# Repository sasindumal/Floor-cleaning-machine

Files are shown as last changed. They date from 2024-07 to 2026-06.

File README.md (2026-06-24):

# 🤖 Autonomous Floor Cleaning Machine — R1

> **Design Prototype Project** | Group R1 | Sasindu Malhara (2022/E/126)

An autonomous floor-cleaning robot designed and built from scratch, featuring dual-mode operation (manual Bluetooth control and ML-powered automatic navigation), custom mechanical design, CoppeliaSim simulation, and a machine learning model embedded directly into Arduino firmware.

---

## 📖 Table of Contents

- [Overview](#overview)
- [Features](#features)
- [System Architecture](#system-architecture)
- [Hardware Components](#hardware-components)
- [Software & Tech Stack](#software--tech-stack)
- [Project Structure](#project-structure)
- [Operating Modes](#operating-modes)
  - [Manual Mode (Bluetooth)](#manual-mode-bluetooth)
  - [Automatic Mode (ML-based)](#automatic-mode-ml-based)
- [Machine Learning Model](#machine-learning-model)
- [Simulation](#simulation)
- [Mechanical Design](#mechanical-design)
- [Code Versions](#code-versions)
- [Pin Configuration](#pin-configuration)
- [Bluetooth Command Reference](#bluetooth-command-reference)
- [Setup & Deployment](#setup--deployment)
- [Reinforcement Learning Notes](#reinforcement-learning-notes)
- [Videos & Demos](#videos--demos)
- [Author](#author)

---

## Overview

The **Autonomous Floor Cleaning Machine R1** is a prototype robotic system capable of navigating indoor environments while performing floor-cleaning tasks. The robot integrates:

- A **dual H-bridge motor driver** (L298N) for differential drive
- **4 ultrasonic sensors** for 360° obstacle detection
- A **Bluetooth module (HC-05)** for wireless manual control
- A **machine learning model** trained on sensor data and compiled into C++ to run directly on an Arduino Uno
- A **roller brush**, **mop**, **water pump**, and **dryer** for complete floor-cleaning functionality
- **SolidWorks CAD** drawings and **CoppeliaSim** simulation models for design validation

---

## Features

- ✅ **Manual Bluetooth Control** — real-time directional commands via serial/Bluetooth
- ✅ **Autonomous Obstacle-Avoidance Navigation** — ML model predicts movement decisions from ultrasonic sensor readings
- ✅ **Embedded ML on Arduino** — trained model converted to C++ (`predict()` function) and flashed to Arduino Uno
- ✅ **Complete Cleaning System** — roller brush, mop motor, water pump, and dryer actuators
- ✅ **Dual-mode switching** — seamlessly switch between manual and auto mode over Bluetooth
- ✅ **CoppeliaSim Simulation** — multiple simulation versions for testing before hardware deployment
- ✅ **SolidWorks CAD** — full mechanical assembly with custom parts
- ✅ **URDF Models** — ROS-compatible robot description files (3 versions)

---

## System Architecture

```
┌─────────────────────────────────────────────────────────┐
│                     Arduino Uno                         │
│                                                         │
│  ┌──────────┐   ┌──────────────┐   ┌─────────────────┐ │
│  │ Bluetooth│   │  Ultrasonic  │   │  ML predict()   │ │
│  │  HC-05   │──▶│  4x Sensors  │──▶│  (C++ model)    │ │
│  └──────────┘   └──────────────┘   └────────┬────────┘ │
│                                             │           │
│  ┌──────────────────────────────────────────▼────────┐  │
│  │              Motor Control (L298N)                │  │
│  │         Left Motor  |  Right Motor                │  │
│  └──────────────────────────────────────────────────┘  │
│                                                         │
│  ┌──────────┐  ┌─────┐  ┌──────┐  ┌─────┐             │
│  │  Roller  │  │ MOP │  │ Pump │  │ Dry │             │
│  │  Brush   │  │Motor│  │      │  │     │             │
│  └──────────┘  └─────┘  └──────┘  └─────┘             │
└─────────────────────────────────────────────────────────┘
```

---

## Hardware Components

| Component | Model / Spec | Purpose |
|---|---|---|
| Microcontroller | Arduino Uno | Main controller |
| Motor Driver | L298N Dual H-Bridge | Controls left & right drive motors |
| Drive Motors | DC Motors (x2) | Differential drive locomotion |
| Ultrasonic Sensors | HC-SR04 (x4) | Front-left, front-right, left, right obstacle detection |
| Bluetooth Module | HC-05 | Wireless serial communication |
| Roller Brush Motor | DC Motor | Floor brushing/sweeping |
| Mop Motor | DC Motor | Wet mopping actuation |
| Water Pump | KDP-370EB 12V | Water dispensing for mopping |
| Dryer | DC Motor | Floor drying after mopping |
| Battery | KT-1213 12V 1.3Ah AGM Lead-Acid | Main power supply |
| Chassis | Custom SolidWorks design | Machine body & mounting |
| Wheels | 85mm custom wheels | Locomotion |
| Vacuum Fan | 80mm vacuum fan | Debris suction |

---

## Software & Tech Stack

| Layer | Technology |
|---|---|
| Firmware | Arduino C++ (.ino) |
| ML Training | Python, Jupyter Notebook, scikit-learn / neural network |
| ML Deployment | C++ model code embedded in Arduino firmware |
| Simulation | CoppeliaSim (.ttt scene files) |
| CAD Design | SolidWorks (.SLDPRT, .SLDASM) |
| Robot Description | URDF (ROS-compatible) |
| Data | CSV dataset for ML training |
| RL Research | Unity ML-Agents (referenced in RL notes) |

---

## Project Structure

```
02 Floor-cleaning-machine/
│
├── Code/                                    # All firmware and software
│   ├── Floor-Cleanig-machine-R1/
│   │   └── Floor-Cleanig-machine-R1.ino    # Revision 1 firmware
│   ├── Floor-Cleanig-machine-R1-Final/
│   │   └── Floor-Cleanig-machine-R1-Final.ino  # Final production firmware
│   ├── Floor_Cleanig_machine_R1_Final_test/
│   │   └── (test sketches)
│   ├── ML/
│   │   ├── Floor-Cleaning-Machine-ML.ipynb  # ML training notebook
│   │   ├── Floor cleaning machine ML dataset.csv  # Training dataset
│   │   ├── model.json                        # Trained model (JSON)
│   │   ├── Floor-Cleaning-Machine-ML.pdf    # ML documentation
│   │   ├── c++ model code.txt               # C++ exported model code
│   │   └── cpp-model-check.cpp              # C++ model integration test
│   ├── US_check/
│   │   └── US_check.ino                     # Ultrasonic sensor test sketch
│   ├── check-sensors/
│   │   └── check-sensors.ino                # Sensor + motor diagnostic sketch
│   ├── Code 2.0.txt                         # Code snapshot v2.0
│   └── Code 3.0.txt                         # Code snapshot v3.0
│
├── Machine/                                 # Mechanical design files
│   ├── CoppeliaSim/
│   │   ├── Machine.ttt                      # Simulation scene v1
│   │   ├── Machine 2.0.ttt                  # Simulation scene v2
│   │   ├── Machine 3.0.ttt                  # Simulation scene v3
│   │   ├── Machine 4.0.ttt                  # Simulation scene v4
│   │   ├── Machine 5.0.ttt                  # Simulation scene v5
│   │   └── Machine-ML/                      # ML-enabled simulation
│   ├── Drawing/                             # SolidWorks parts & assembly
│   │   ├── Machine.SLDASM                   # Full machine assembly
│   │   ├── Body.SLDPRT                      # Machine body
│   │   ├── Arduino Uno.SLDPRT              # Arduino Uno model
│   │   ├── HCSR04 Ultrasonic Sensor.SLDPRT # HC-SR04 model
│   │   ├── L298N_Stepper_motor_driver.SLDPRT
│   │   ├── Roller Brush.SLDPRT
│   │   ├── 85mm_Wheel.SLDPRT
│   │   ├── KT-1213 Battery.SLDASM          # Battery assembly
│   │   └── ... (27 component files total)
│   ├── URDF/                                # ROS robot description v1
│   ├── URDF 2.0/                            # ROS robot description v2
│   └── URDF 3.0/                            # ROS robot description v3
│
├── RL/
│   └── Rl steps.txt                         # Reinforcement learning research notes
│
├── Videos/                                  # Physical build & simulation demos
│   ├── Simulation.mkv                       # CoppeliaSim simulation video
│   ├── Cad design.mkv                       # SolidWorks CAD walkthrough
│   └── VID-20240806-*.mp4                   # Physical prototype test videos
│
├── .gitignore
└── README.md
```

---

## Operating Modes

### Manual Mode (Bluetooth)

The robot defaults to **manual mode** on startup. Commands are sent via the HC-05 Bluetooth module (serial at 9600 baud).

The robot receives a single character over serial and executes the corresponding action:

| Command | Action |
|---|---|
| `F` | Move **Forward** + activate pump |
| `f` | Stop (forward stop) |
| `B` | Move **Backward** |
| `b` | Stop (backward stop) |
| `L` | Turn **Left** |
| `l` | Stop (left stop) |
| `R` | Turn **Right** |
| `r` | Stop (right stop) |
| `S` | **Stop** all drive motors |
| `N` | Turn **Pump ON** |
| `n` | Turn **Pump OFF** |
| `M` | Turn **Mop Motor ON** |
| `m` | Turn **Mop Motor OFF** |
| `K` | Turn **Roller Brush ON** |
| `k` | Turn **Roller Brush OFF** |
| `D` | Turn **Dryer ON** |
| `d` | Turn **Dryer OFF** |
| `A` | Switch to **Automatic Mode** |

### Automatic Mode (ML-based)

Activated by sending `A` over Bluetooth. The robot:

1. **Reads** all 4 ultrasonic sensors (front-left, front-right, left, right)
2. **Feeds** the sensor distances into the embedded `predict()` function (C++ ML model)
3. **Executes** the predicted movement command:

| Prediction | Action |
|---|---|
| `0` | Turn Left |
| `1` | Turn Right |
| `2` | Move Backward |
| `3` | Move Forward |

Send `X` to exit automatic mode and return to manual control.

---

## Machine Learning Model

The navigation decision model was trained in Python using sensor distance data.

### Training Pipeline

1. **Dataset**: `Floor cleaning machine ML dataset.csv` — collected sensor readings labeled with correct movement decisions
2. **Training**: Jupyter Notebook (`Floor-Cleaning-Machine-ML.ipynb`) — model trained using scikit-learn / neural network
3. **Export**: Model exported to `model.json` and converted to C++ code (`c++ model code.txt`)
4. **Deployment**: The C++ `predict(float[])` function is compiled directly into Arduino firmware — **no external libraries or runtime needed**

### Inputs / Outputs

```
Inputs:  [front_distance, left_distance, right_distance]  (float, in cm)
Output:  int prediction -> { 0: Left, 1: Right, 2: Backward, 3: Forward }
```

---

## Simulation

CoppeliaSim simulation scenes are located in `Machine/CoppeliaSim/`. Multiple versions were developed iteratively:

| File | Version | Description |
|---|---|---|
| `Machine.ttt` | v1.0 | Initial simulation |
| `Machine 2.0.ttt` | v2.0 | Updated physics |
| `Machine 3.0.ttt` | v3.0 | Sensor integration |
| `Machine 4.0.ttt` | v4.0 | Full sensor + motor simulation |
| `Machine 5.0.ttt` | v5.0 | Final simulation |
| `Machine-ML/` | ML | ML-integrated simulation |

A simulation demo video is available at `Videos/Simulation.mkv`.

---

## Mechanical Design

The machine body was designed in **SolidWorks** with a full assembly (`Machine.SLDASM`) comprising 27 custom and standard parts:

- Custom body chassis and mounting brackets
- DC motor + bracket assemblies
- 85mm drive wheels
- Roller brush assembly
- HC-SR04 ultrasonic sensor mounts
- L298N motor driver mount
- Arduino Uno and HC-05 Bluetooth module placements
- 12V AGM lead-acid battery compartment
- 80mm vacuum fan housing

A CAD design walkthrough video is available at `Videos/Cad design.mkv`.

**URDF models** (3 versions) are provided for ROS-based simulation or further robot modeling.

---

## Code Versions

| Version | File | Description |
|---|---|---|
| v1.0 (R1) | `Code/Floor-Cleanig-machine-R1/Floor-Cleanig-machine-R1.ino` | Initial prototype firmware |
| v2.0 | `Code/Code 2.0.txt` | Intermediate version snapshot |
| v3.0 | `Code/Code 3.0.txt` | Feature-complete snapshot |
| v1-Final | `Code/Floor-Cleanig-machine-R1-Final/Floor-Cleanig-machine-R1-Final.ino` | **Production firmware with embedded ML** |
| Test | `Code/Floor_Cleanig_machine_R1_Final_test/` | Test sketches |
| Sensor check | `Code/check-sensors/check-sensors.ino` | Sensor + motor diagnostic |
| US check | `Code/US_check/US_check.ino` | Ultrasonic-only diagnostic |

---

## Pin Configuration

### Drive Motors (via L298N)

| Pin | Arduino | Function |
|---|---|---|
| `L1` | D2 | Left motor direction A |
| `L2` | D4 | Left motor direction B |
| `LENB` | D3 (PWM) | Left motor enable (speed) |
| `R1` | D5 (PWM) | Right motor direction A |
| `R2` | D7 | Right motor direction B |
| `RENB` | D6 (PWM) | Right motor enable (speed) |

### Cleaning Actuators

| Pin | Arduino | Function |
|---|---|---|
| `Roller` | D8 | Roller brush motor |
| `MOP` | D9 | Mop motor |
| `Pump` | D12 | Water pump |
| `Dry` | D11 | Dryer motor |

### Ultrasonic Sensors (HC-SR04)

| Sensor | Trig Pin | Echo Pin |
|---|---|---|
| Front-Left (`Usfl`) | A1 | A0 |
| Front-Right (`Usfr`) | D13 | D10 |
| Left (`Usl`) | A3 | A2 |
| Right (`Usr`) | A5 | A4 |

---

## Bluetooth Command Reference

Connect a Bluetooth terminal app (e.g., **Serial Bluetooth Terminal** on Android) to the HC-05 module:

- **Baud rate**: `9600`
- **Device name**: `HC-05` (default)
- **Pairing PIN**: `1234` or `0000`

Send single characters as listed in the [Manual Mode](#manual-mode-bluetooth) section above.

---

## Setup & Deployment

### Prerequisites

- [Arduino IDE](https://www.arduino.cc/en/software) (v1.8+ or v2.x)
- [CoppeliaSim](https://www.coppeliarobotics.com/) (for simulation)
- [SolidWorks](https://www.solidworks.com/) (for CAD files)
- Python 3.x + Jupyter Notebook (for ML training)

### Flash Firmware

1. Open `Code/Floor-Cleanig-machine-R1-Final/Floor-Cleanig-machine-R1-Final.ino` in Arduino IDE
2. Select **Board**: `Arduino Uno`
3. Select the correct **Port** for your connected Arduino
4. Click **Upload**

### Run Simulation

1. Open CoppeliaSim
2. Load `Machine/CoppeliaSim/Machine 5.0.ttt` (latest simulation)
3. Press **Play** to start the simulation

### Retrain ML Model (Optional)

1. Open `Code/ML/Floor-Cleaning-Machine-ML.ipynb` in Jupyter Notebook
2. Ensure the dataset `Floor cleaning machine ML dataset.csv` is in the same directory
3. Run all cells to retrain and export the model
4. Copy the generated C++ `predict()` function into the main `.ino` firmware file

---

## Reinforcement Learning Notes

The `RL/Rl steps.txt` file documents research into using **Reinforcement Learning** (RL) as an alternative navigation approach:

- **Simulation environment**: Unity with ML-Agents Toolkit
- **Algorithm considered**: PPO (Proximal Policy Optimization), DQN (Deep Q-Networks)
- **Reward design**: Obstacle avoidance + staying on track
- **Deployment challenge**: Converting RL model for Arduino's limited hardware

> The current production firmware uses a **supervised ML model** (trained on labeled sensor data) rather than RL, as it is more practical for Arduino deployment.

---

## Videos & Demos

| File | Description |
|---|---|
| `Videos/Simulation.mkv` | CoppeliaSim simulation demo |
| `Videos/Cad design.mkv` | SolidWorks CAD design walkthrough |
| `Videos/VID-20240806-WA0002.mp4` | Physical prototype test |
| `Videos/VID-20240806-WA0009.mp4` | Obstacle avoidance test |
| `Videos/VID-20240806-WA0015.mp4` | Full cleaning run demo |
| `Videos/2024-08-08 08-30-12.mkv` | Final build test session |

---

## Author

**Sasindu Malhara** — `2022/E/126`
Group R1 — Design Prototype Project

---

*This project was developed as a design prototype for academic purposes. All code and design files are owned by Group R1.*

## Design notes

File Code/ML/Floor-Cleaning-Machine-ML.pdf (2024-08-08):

## Floor-Cleaning-Machine-ML

August 8, 2024

## 1 Floor Cleaning Machine ML Model with Random Forest

This code is fully owned by Sasindu Malhara (2022/E/126,University of jaffna) group R1.

### 1.0.1 Import libraries

[1]: import pandas as pd
from sklearn.model_selection import train_test_split from sklearn.ensemble import RandomForestClassifier import json
from sklearn.metrics import accuracy_score

### 1.0.2 Import data

[2]: data=pd.read_csv("D:\\Sem 3 - E22\\E22\\DP\\Our\\2. ↪0\\Git\\Floor-cleaning-machine\\Code\\ML\\Floor cleaning machine ML dataset . ↪csv")

### 1.0.3 Data mapping

[3]: data['next movement'] = data['next movement'].map({' L': 0, 'R': 1, 'B': 2, 'F': ↪ 3})

[4]: data.fillna(0, inplace=True)

[5]: X = data.drop('next movement', axis=1) y = data['next movement']

[6]: X

[6]: | Usf Usl Usr
0 | 1 | 0 | 0
1 | 1 | 1 | 0
2 | 1 | 0 | 1
3 | 1 | 1 | 1
4 | 0 | 0 | 0
59 | 1 | 1 | 1

60 | 0 | 0 | 0
61 | 0 | 1 | 1
62 | 0 | 1 | 0
63 | 0 | 0 | 1

[64 rows x 3 columns]

[7]: y

[7]: 0 | 1.0
1 | 1.0
2 | 0.0
3 | 2.0
4 | 3.0
…
59 | 2.0
60 | 3.0
61 | 3.0
62 | 3.0
63 | 3.0
Name: next movement, Length: 64, dtype: float64

[8]: print('X.shape=', X.shape, 'y.shape=', y.shape)

X.shape= (64, 3) y.shape= (64,)

### 1.0.4 Splitting data

[9]: X_train, X_test, y_train, y_test = train_test_split(X, y, test_size=0.2,␣ ↪random_state=42)

### 1.0.5 Finding best parameters

[11]: from sklearn.model_selection import RandomizedSearchCV from scipy.stats import randint

param_dist = {
'n_estimators': randint(100, 1000), 'max_features': ['auto', 'sqrt', 'log2'], 'max_depth': randint(4, 20), 'min_samples_split': randint(2, 10), 'min_samples_leaf': randint(1, 4), 'bootstrap': [True, False]
}

rf = RandomForestClassifier()
random_search = RandomizedSearchCV(estimator = rf, param_distributions =␣ ↪param_dist, n_iter = 100, cv = 3, n_jobs = -1, verbose =␣ ↪2)
random_search.fit(X_train, y_train)
best_params = random_search.best_params_

Fitting 3 folds for each of 100 candidates, totalling 300 fits

c:\Users\sasin\anaconda3\Lib\site-packages\sklearn\ensemble\_forest.py:424: FutureWarning: `max_features='auto'` has been deprecated in 1.1 and will be removed in 1.3. To keep the past behaviour, explicitly set `max_features='sqrt'` or remove this parameter as it is also the default value for

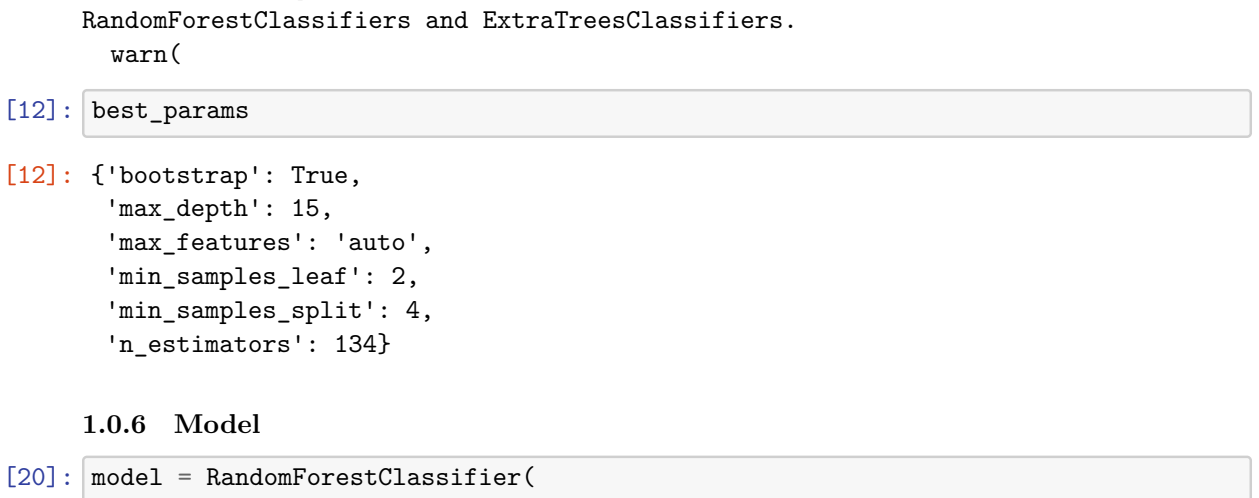
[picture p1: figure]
RandomForestClassifiers and ExtraTreesClassifiers. warn(; [12]: best_params; [12]: {'bootstrap': True, 'max_depth': 15, 'max_features': 'auto', 'min_samples_leaf': 2, 'min_samples_split': 4, 'n_estimators': 134}; 1.0.6 Model; [20]: model = RandomForestClassifier(

bootstrap=True,
max_depth=3,
max_features='auto',
min_samples_leaf=2,
min_samples_split=4,
n_estimators=10
)
model.fit(X_train, y_train)

c:\Users\sasin\anaconda3\Lib\site-packages\sklearn\ensemble\_forest.py:424: FutureWarning: `max_features='auto'` has been deprecated in 1.1 and will be removed in 1.3. To keep the past behaviour, explicitly set `max_features='sqrt'` or remove this parameter as it is also the default value for

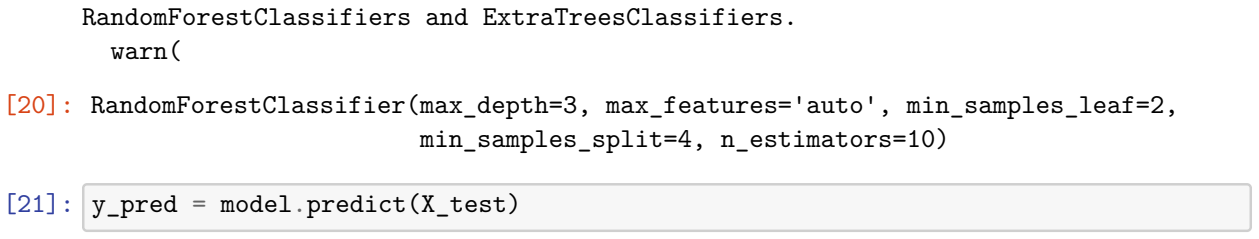
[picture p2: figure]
RandomForestClassifiers and ExtraTreesClassifiers. warn(; [20]: RandomForestClassifier(max_depth=3, max_features='auto', min_samples_leaf=2, min_samples_split=4, n_estimators=10); [21]: y_pred = model.predict(X_test)

### 1.0.7 Evaluating model

[22]: accuracy = accuracy_score(y_test, y_pred) print(f'Accuracy: {accuracy:.2f}')

Accuracy: 1.00

### 1.0.8 Predicting

[17]: # Sample input
sample_input = [[0, 0, 1, ]]

# Predict

y_pred = model.predict(sample_input)

print("Predicted class:", y_pred)

Predicted class: [3.]

c:\Users\sasin\anaconda3\Lib\site-packages\sklearn\base.py:439: UserWarning: X does not have valid feature names, but RandomForestClassifier was fitted with feature names
warnings.warn(

[18]: next_movement_mapping = {0: 'L', 1: 'R', 2: 'B', 3: 'F'}
predicted_movement = next_movement_mapping[y_pred[0]] print(f'Predicted next movement: {predicted_movement}')

Predicted next movement: F

### 1.0.9 Converting the model to c++ for inject Arduino

[23]: from micromlgen import port
from sklearn.ensemble import RandomForestClassifier import json

# Convert the model to C code

c_code = port(model, platform='arduino') print(c_code)

#pragma once

#include <cstdarg>

namespace Eloquent {
namespace ML {
namespace Port {
class RandomForest {
public:
/**
* Predict class for features vector

*/
int predict(float *x) {
uint8_t votes[4] = { 0 };
// tree #1
if (x[0] <= 0.5) {
votes[3] += 1;
}

else {
if (x[1] <= 0.5) {
if (x[2] <= 0.5) {
votes[1] += 1;
}

else {
votes[0] += 1;
}
}

else {
if (x[2] <= 0.5) {
votes[1] += 1;
}

else {
votes[2] += 1;
}
}
}

// tree #2
if (x[2] <= 0.5) {
if (x[0] <= 0.5) {
votes[3] += 1;
}

else {
votes[1] += 1;
}
}

else {
if (x[0] <= 0.5) {
votes[3] += 1;
}

else {
if (x[1] <= 0.5) {

votes[0] += 1;
}

else {
votes[2] += 1;
}
}
}

// tree #3
if (x[0] <= 0.5) {
votes[3] += 1;
}

else {
if (x[1] <= 0.5) {
if (x[2] <= 0.5) {
votes[1] += 1;
}

else {
votes[0] += 1;
}
}

else {
if (x[2] <= 0.5) {
votes[1] += 1;
}

else {
votes[2] += 1;
}
}
}

// tree #4
if (x[2] <= 0.5) {
if (x[1] <= 0.5) {
if (x[0] <= 0.5) {
votes[3] += 1;
}

else {
votes[1] += 1;
}
}

else {
if (x[0] <= 0.5) {
votes[3] += 1;
}

else {
votes[1] += 1;
}
}
}

else {
if (x[0] <= 0.5) {
votes[3] += 1;
}

else {
if (x[1] <= 0.5) {
votes[0] += 1;
}

else {
votes[2] += 1;
}
}
}

// tree #5
if (x[0] <= 0.5) {
votes[3] += 1;
}

else {
if (x[2] <= 0.5) {
votes[1] += 1;
}

else {
if (x[1] <= 0.5) {
votes[0] += 1;
}

else {
votes[2] += 1;
}
}
}

// tree #6
if (x[1] <= 0.5) {
if (x[0] <= 0.5) {
votes[3] += 1;
}

else {
if (x[2] <= 0.5) {
votes[1] += 1;
}

else {
votes[0] += 1;
}
}
}

else {
if (x[0] <= 0.5) {
votes[3] += 1;
}

else {
if (x[2] <= 0.5) {
votes[1] += 1;
}

else {
votes[2] += 1;
}
}
}

// tree #7
if (x[2] <= 0.5) {
if (x[0] <= 0.5) {
votes[3] += 1;
}

else {
votes[1] += 1;
}
}

else {
if (x[0] <= 0.5) {
votes[3] += 1;
}

else {
if (x[1] <= 0.5) {
votes[0] += 1;
}

else {
votes[2] += 1;
}
}
}

// tree #8
if (x[2] <= 0.5) {
if (x[1] <= 0.5) {
if (x[0] <= 0.5) {
votes[3] += 1;
}

else {
votes[1] += 1;
}
}

else {
if (x[0] <= 0.5) {
votes[3] += 1;
}

else {
votes[1] += 1;
}
}
}

else {
if (x[1] <= 0.5) {
if (x[0] <= 0.5) {
votes[3] += 1;
}

else {
votes[0] += 1;
}
}

else {
if (x[0] <= 0.5) {

votes[3] += 1;
}

else {
votes[2] += 1;
}
}
}

// tree #9
if (x[1] <= 0.5) {
if (x[0] <= 0.5) {
votes[3] += 1;
}

else {
if (x[2] <= 0.5) {
votes[1] += 1;
}

else {
votes[0] += 1;
}
}
}

else {
if (x[0] <= 0.5) {
votes[3] += 1;
}

else {
if (x[2] <= 0.5) {
votes[1] += 1;
}

else {
votes[2] += 1;
}
}
}

// tree #10
if (x[1] <= 0.5) {
if (x[2] <= 0.5) {
if (x[0] <= 0.5) {
votes[3] += 1;
}

else {
votes[1] += 1;
}
}

else {
if (x[0] <= 0.5) {
votes[3] += 1;
}

else {
votes[0] += 1;
}
}
}

else {
if (x[0] <= 0.5) {
votes[3] += 1;
}

else {
votes[2] += 1;
}
}

// return argmax of votes
uint8_t classIdx = 0;
float maxVotes = votes[0];

for (uint8_t i = 1; i < 4; i++) { if (votes[i] > maxVotes) { classIdx = i;
maxVotes = votes[i];
}
}

return classIdx;
}

protected:
};
}
}
}

[ ]:

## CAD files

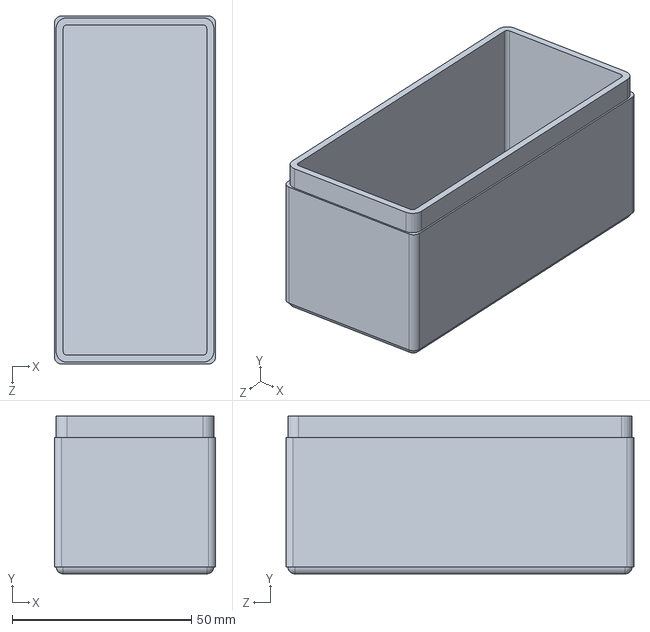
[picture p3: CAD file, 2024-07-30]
Machine/Drawing/Main Body, KT-1213, 12 V, 1.3 Ah, AGM Lead-Acid Battery.SLDPRT
45.0 x 44.0 x 97.0 mm

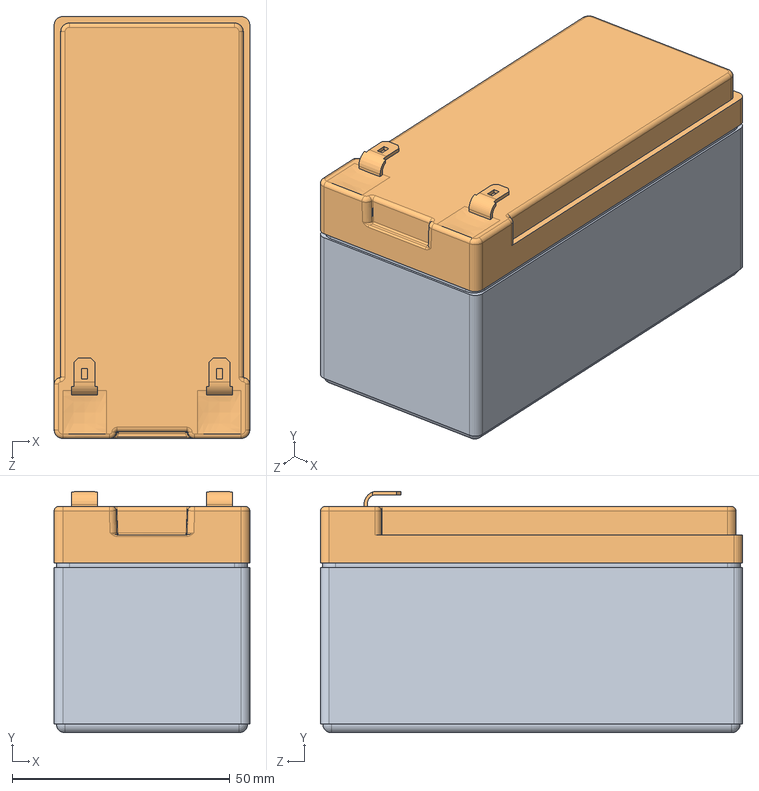
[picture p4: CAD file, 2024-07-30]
Machine/Drawing/KT-1213, 12 V, 1.3 Ah, AGM Lead-Acid Battery.SLDASM
45.0 x 55.5 x 97.0 mm
Main Body, KT-1213, 12 V, 1.3 Ah, AGM Lead-Acid Battery
Cover, KT-1213, 12 V, 1.3 Ah, AGM Lead-Acid Battery

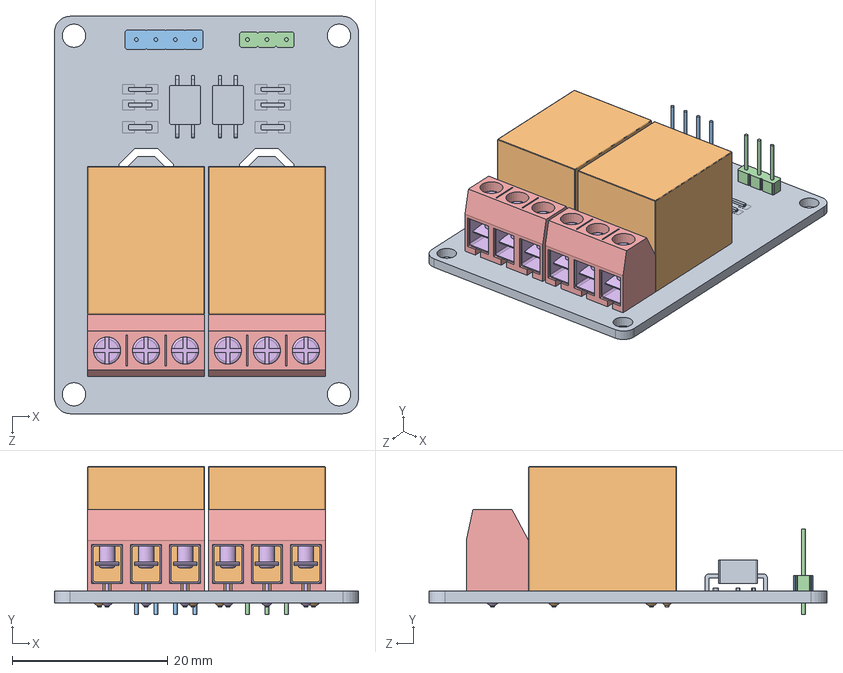
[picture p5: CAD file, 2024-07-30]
Machine/Drawing/Relay - 2 Channel - 2PH63091A - Montaj.SLDASM
39.0 x 19.0 x 51.0 mm
2PH63091A Board
Relay Body x 2
4 Headers
Headers
Clamp Body x 2
Metal Clamp Part x 6

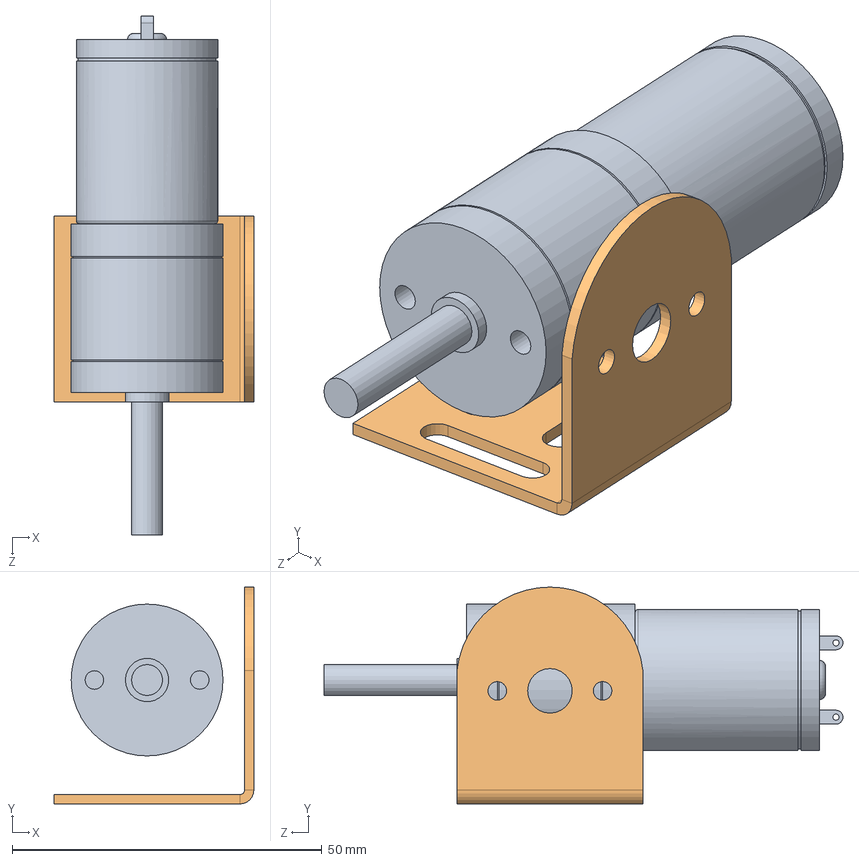
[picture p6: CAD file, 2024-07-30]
Machine/Drawing/DC motor 1.1.SLDASM
32.2 x 35.0 x 83.8 mm
Dc motor 2
DC motor Bracket

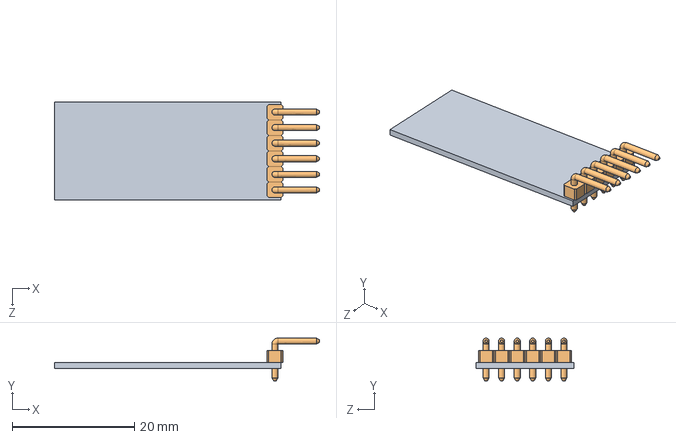
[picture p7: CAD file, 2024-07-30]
Machine/Drawing/Bluetooth Modul HC 05.SLDASM
43.3 x 7.00 x 16.0 mm
Bluetooth Modul HC 05 Board
Male L Header x 6

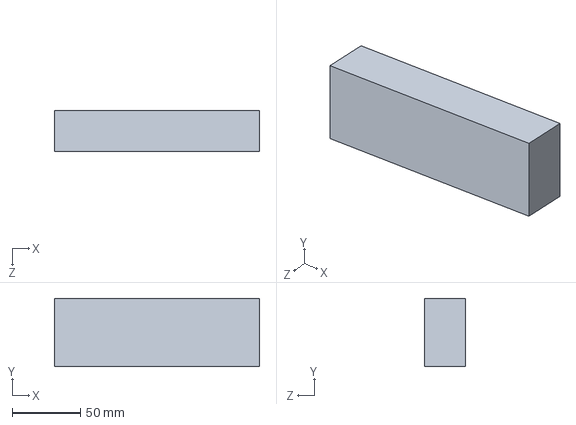
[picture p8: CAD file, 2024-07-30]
Machine/Drawing/Mopping motor setter.SLDPRT
150.0 x 50.0 x 30.0 mm

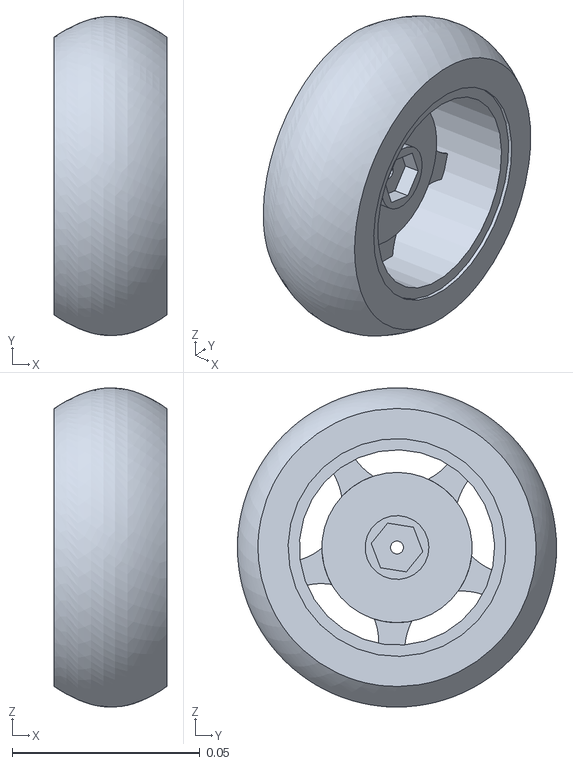
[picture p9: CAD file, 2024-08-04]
Machine/URDF 2.0/meshes/FR.STL
0.03 x 0.0849 x 0.0849

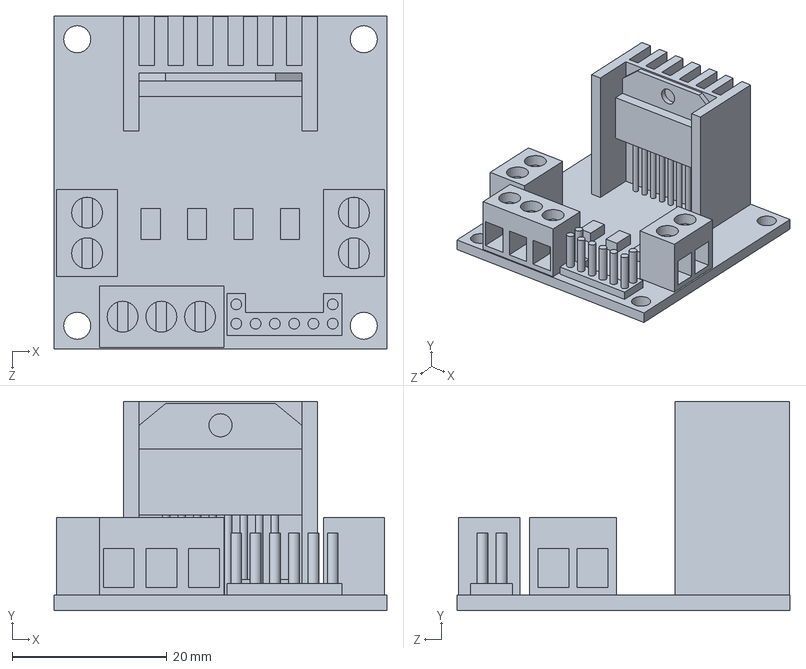
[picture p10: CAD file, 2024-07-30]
Machine/Drawing/L298N_Stepper_motor_driver.SLDPRT
43.0 x 27.0 x 43.0 mm

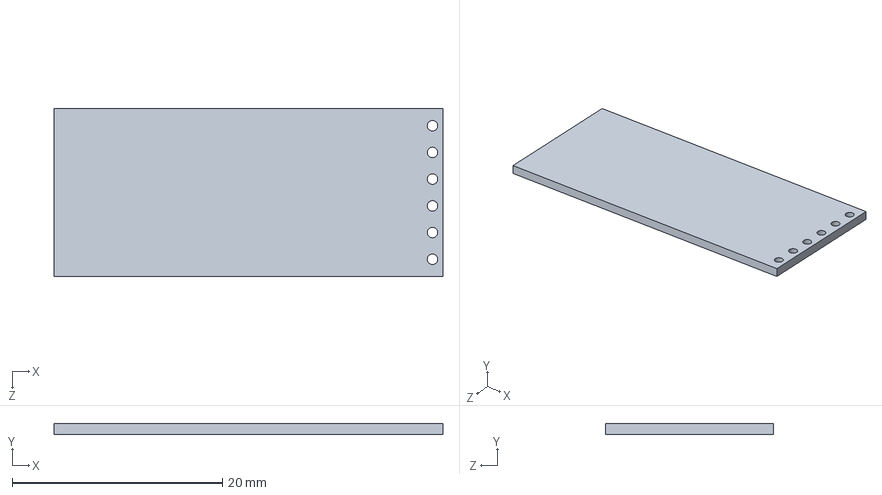
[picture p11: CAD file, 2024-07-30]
Machine/Drawing/Bluetooth Modul HC 05 Board.SLDPRT
37.0 x 1.00 x 16.0 mm

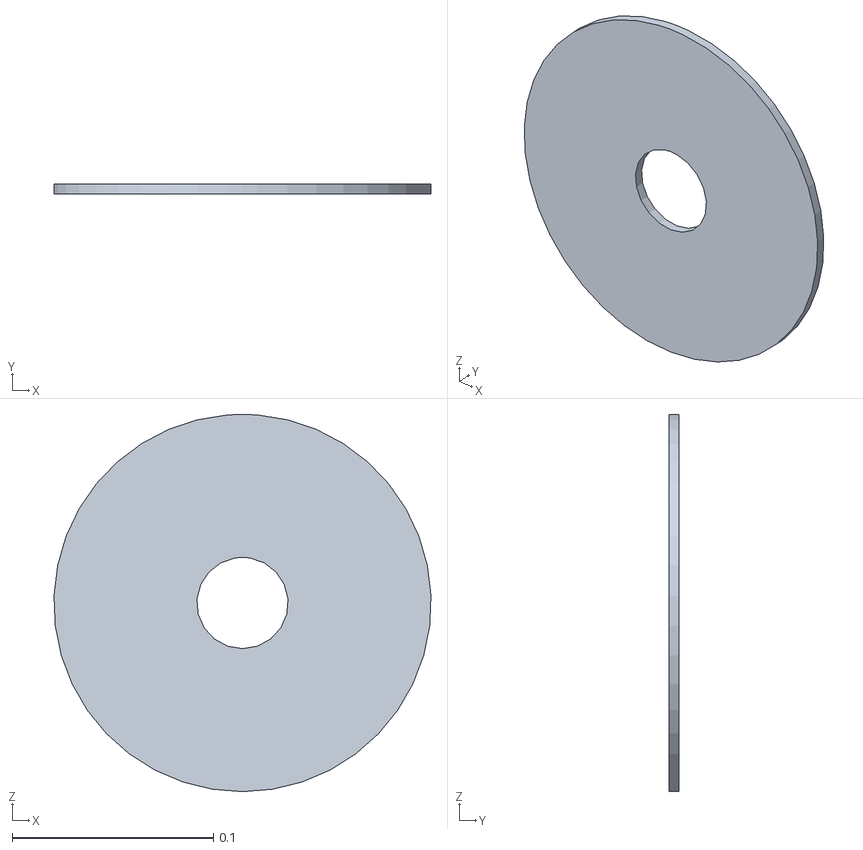
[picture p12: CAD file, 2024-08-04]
Machine/URDF 3.0/meshes/ML.STL
0.187 x 0.005 x 0.187

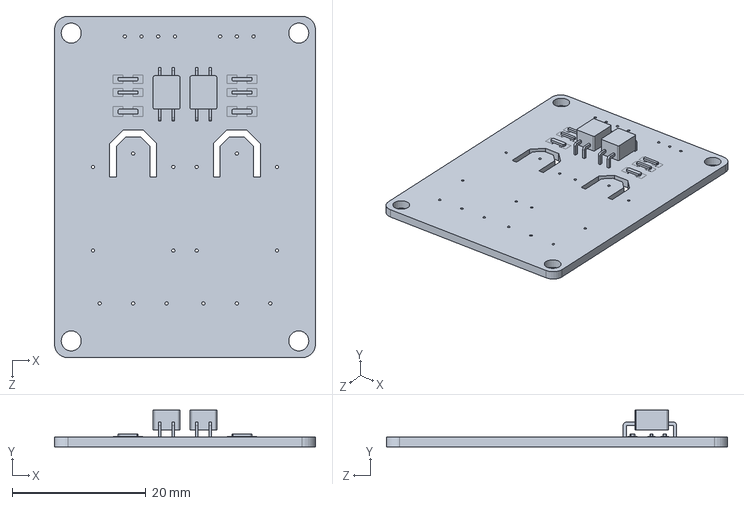
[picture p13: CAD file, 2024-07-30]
Machine/Drawing/2PH63091A Board.SLDPRT
39.0 x 5.50 x 51.0 mm

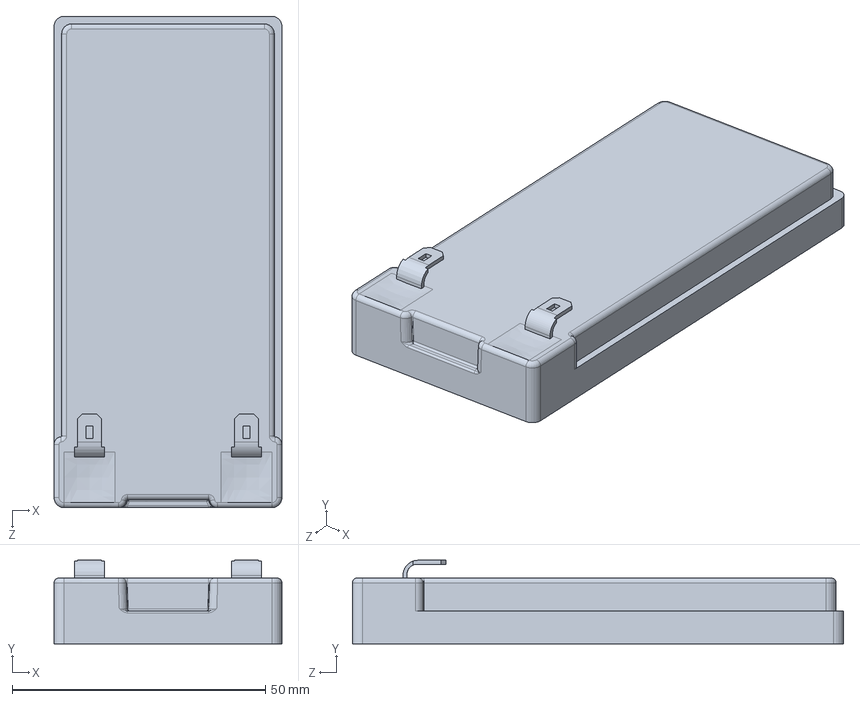
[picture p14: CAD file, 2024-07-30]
Machine/Drawing/Cover, KT-1213, 12 V, 1.3 Ah, AGM Lead-Acid Battery.SLDPRT
45.0 x 16.5 x 97.0 mm

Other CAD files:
Machine/URDF 3.0/meshes/BR.STL
Machine/URDF 2.0/meshes/BL.STL
Machine/URDF 3.0/meshes/BL.STL
Machine/URDF 2.0/meshes/FL.STL
Machine/URDF 2.0/meshes/BR.STL
Machine/URDF 3.0/meshes/FL.STL
Machine/Drawing/4 Headers.SLDPRT
Machine/Drawing/80mm Vacum fan .SLDPRT
Machine/Drawing/Body.SLDPRT
Machine/Drawing/Clamp Body.SLDPRT
Machine/Drawing/DC motor Bracket.SLDPRT
Machine/Drawing/Dc motor 2.SLDPRT
Machine/Drawing/HCSR04 Ultrasonic Sensor.SLDPRT
Machine/Drawing/Headers.SLDPRT
Machine/Drawing/KDP-370EB12v.SLDPRT
Machine/Drawing/Male L Header.SLDPRT
Machine/Drawing/Metal Clamp Part.SLDPRT
Machine/Drawing/Part2.SLDPRT
Machine/Drawing/Relay Body.SLDPRT
Machine/Drawing/Roller Brush.SLDPRT
Machine/URDF 2.0/meshes/ML.STL
Machine/URDF 2.0/meshes/MR.STL
Machine/URDF 2.0/meshes/Roller.STL
Machine/URDF 3.0/meshes/FR.STL
Machine/URDF 3.0/meshes/MR.STL
Machine/URDF 3.0/meshes/Roller.STL

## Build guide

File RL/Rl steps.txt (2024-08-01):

Creating a reinforcement learning (RL) self-driving car using Arduino involves several key steps. Here’s a general guide to get you started:

Hardware Setup:

Arduino Board: Choose a suitable Arduino board (e.g., Arduino Uno).
Motors and Wheels: Attach motors and wheels to your car chassis.
Sensors: Integrate sensors such as ultrasonic sensors for obstacle detection and IR sensors for line tracking.
Power Supply: Ensure a stable power supply for all components.
Environment Setup:

Create a track with clear markings for the car to follow. This could be a simple line on the floor or a more complex track with obstacles.
Reinforcement Learning Model:

Training Environment: Use a simulation environment like Unity to train the RL model. This allows you to simulate the car’s movements and interactions with the environment without hardware limitations [3].
Training: Implement and train the RL algorithm (e.g., Q-learning, Deep Q-Networks) to learn optimal driving policies.
Model Deployment:

Model Conversion: Convert the trained model into a format compatible with Arduino (e.g., by simplifying the model or using a smaller neural network) [2].
Arduino Coding: Write Arduino code to deploy the trained model. The code should read sensor data, process it using the trained model, and send control commands to the motors.
Testing and Iteration:

Initial Testing: Test the car in a controlled environment to evaluate performance.
Refinement: Fine-tune the model and the Arduino code based on test results. Iteratively improve the system for better performance and reliability [1].
By following these steps, you can build a basic RL-based self-driving car using Arduino. This project will involve a combination of hardware setup, software development, and machine learning model training.

To train a Reinforcement Learning (RL) model for an autonomous vehicle using a simulation environment like Unity, follow these steps:

Set Up Unity Environment:

Install Unity: Download and install Unity Hub and the latest version of Unity Editor.
Create a New Project: Start a new 3D project in Unity.
Import ML-Agents: Add the Unity ML-Agents Toolkit to your project. You can do this via Unity Package Manager or by downloading it from GitHub.
Design Simulation Environment:

Build the Scene: Create a virtual track or environment where the car will operate. Add obstacles and define the boundaries.
Add Car Model: Import or create a 3D model of the car and set up its physics properties.
Configure ML-Agents:

Create Agent Script: Write a custom agent script for your car. This script will handle actions, observations, and rewards.
Define Actions: Define what actions the car can take (e.g., move forward, turn left, turn right).
Define Observations: Specify the inputs the agent will observe, such as distance to obstacles from ultrasonic sensors.
Set Rewards: Design the reward system to encourage desired behaviors (e.g., avoiding obstacles, staying on track).
Training the RL Algorithm:

Choose an Algorithm: Select an RL algorithm like Proximal Policy Optimization (PPO) or Deep Q-Networks (DQN).
Configure Training Parameters: Set the training parameters in the ML-Agents configuration file (hyperparameters, training steps, etc.).
Start Training: Use the ML-Agents toolkit to start the training process. The agent will interact with the environment, learn from experiences, and update its policy.
Monitor and Evaluate Training:

Track Performance: Monitor the training process using TensorBoard to visualize reward trends and other metrics.
Adjust Hyperparameters: Tune the hyperparameters if the agent's performance is not satisfactory.
Export and Deploy Model:

Save the Trained Model: Once training is complete, save the trained model.
Export to Arduino: If needed, convert the trained model to a format that can be implemented on Arduino. This might involve simplifying the model due to Arduino's hardware limitations.
Example Code Snippet for Unity ML-Agents Agent Script

using UnityEngine;
using Unity.MLAgents;
using Unity.MLAgents.Sensors;
using Unity.MLAgents.Actuators;

public class CarAgent : Agent
{
    public Transform target;
    public float speed = 10f;

    public override void OnEpisodeBegin()
    {
        // Reset car and environment for new episode
        transform.localPosition = Vector3.zero;
        transform.localRotation = Quaternion.identity;
    }

    public override void CollectObservations(VectorSensor sensor)
    {
        // Add observations (e.g., distance to target, obstacles)
        sensor.AddObservation(Vector3.Distance(transform.localPosition, target.localPosition));
        sensor.AddObservation(transform.localPosition);
    }

    public override void OnActionReceived(ActionBuffers actionBuffers)
    {
        // Get actions from the model
        var continuousActions = actionBuffers.ContinuousActions;
        float move = continuousActions[0];
        float turn = continuousActions[1];

        // Apply actions to the car
        transform.Translate(Vector3.forward * move * speed * Time.deltaTime);
        transform.Rotate(Vector3.up, turn * speed * Time.deltaTime);

        // Reward and penalty logic
        float distanceToTarget = Vector3.Distance(transform.localPosition, target.localPosition);
        if (distanceToTarget < 1.5f)
        {
            SetReward(1.0f);
            EndEpisode();
        }
        else
        {
            SetReward(-0.01f);
        }
    }

    public override void Heuristic(in ActionBuffers actionsOut)
    {
        var continuousActionsOut = actionsOut.ContinuousActions;
        continuousActionsOut[0] = Input.GetAxis("Vertical");
        continuousActionsOut[1] = Input.GetAxis("Horizontal");
    }
}

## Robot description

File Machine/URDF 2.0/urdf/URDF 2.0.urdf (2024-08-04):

<?xml version="1.0" encoding="utf-8"?>
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
<robot name="URDF 2.0">
  <link name="base_link">
    <inertial>
      <origin xyz="-0.0597485302559153 0.0141254257572485 0.10587011505937" rpy="0 0 0" />
      <mass value="11.1719906867681" />
      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
    </inertial>
    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
  </link>
  <link name="FL">
    <inertial>
      <origin xyz="0.209204545115889 -0.0199994639772599 0.130181315529934" rpy="0 0 0" />
      <mass value="0.0950105358602906" />
      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
    </inertial>
    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
  </link>
  <joint name="FL" type="revolute">
    <origin xyz="0 0 0" rpy="0 0 0" />
    <parent link="base_link" />
    <child link="FL" />
    <axis xyz="1 0 0" />
    <limit lower="0" upper="0" effort="0" velocity="0" />
  </joint>
  <link name="BL">
    <inertial>
      <origin xyz="0.206514702389292 -0.0186495835920506 -0.139796801281042" rpy="0 0 0" />
      <mass value="0.0950105281619692" />
      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
    </inertial>
    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
  </link>
  <joint name="BL" type="revolute">
    <origin xyz="0 0 0" rpy="0 0 0" />
    <parent link="base_link" />
    <child link="BL" />
    <axis xyz="1 0 0" />
    <limit lower="0" upper="0" effort="0" velocity="0" />
  </joint>
  <link name="BR">
    <inertial>
      <origin xyz="-0.333125105824471 -0.0199996839453711 -0.138583628171085" rpy="0 0 0" />
      <mass value="0.0950105229485309" />
      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
    </inertial>
    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
  </link>
  <joint name="BR" type="revolute">
    <origin xyz="0 0 0" rpy="0 0 0" />
    <parent link="base_link" />
    <child link="BR" />
    <axis xyz="-1 0 0" />
    <limit lower="0" upper="0" effort="0" velocity="0" />
  </joint>
  <link name="FR">
    <inertial>
      <origin xyz="-0.333105988919058 -0.0199992375133413 0.13018188589995" rpy="0 0 0" />
      <mass value="0.0950105229485304" />
      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
    </inertial>
    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
  </link>
  <joint name="FR" type="revolute">
    <origin xyz="0 0 0" rpy="0 0 0" />
    <parent link="base_link" />
    <child link="FR" />
    <axis xyz="-1 0 0" />
    <limit lower="0" upper="0" effort="0" velocity="0" />
  </joint>
  <link name="Roller">
    <inertial>
      <origin xyz="-0.0618941629050707 0.0433404423844075 0.182555550312699" rpy="0 0 0" />
      <mass value="0.353139548782217" />
      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
    </inertial>
    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
  </link>
  <joint name="Roller" type="revolute">
    <origin xyz="0 0 0" rpy="0 0 0" />
    <parent link="base_link" />
    <child link="Roller" />
    <axis xyz="-1 0 0" />
    <limit lower="0" upper="0" effort="0" velocity="0" />
  </joint>
  <link name="ML">
    <inertial>
      <origin xyz="0.0304189041753943 -0.0544952737102189 -0.0327592849498728" rpy="0 0 0" />
      <mass value="0.129817069335416" />
      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
    </inertial>
    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
  </link>
  <joint name="ML" type="revolute">
    <origin xyz="0 0 0" rpy="0 0 0" />
    <parent link="base_link" />
    <child link="ML" />
    <axis xyz="0 -1 0" />
    <limit lower="0" upper="0" effort="0" velocity="0" />
  </joint>
  <link name="MR">
    <inertial>
      <origin xyz="-0.159848061503955 -0.0535340956726708 -0.032114317310548" rpy="0 0 0" />
      <mass value="0.129817069335416" />
      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
    </inertial>
    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
  </link>
  <joint name="MR" type="revolute">
    <origin xyz="0 0 0" rpy="0 0 0" />
    <parent link="base_link" />
    <child link="MR" />
    <axis xyz="0 -1 0" />
    <limit lower="0" upper="0" effort="0" velocity="0" />
  </joint>
</robot>

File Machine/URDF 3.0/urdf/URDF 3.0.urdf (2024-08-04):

<?xml version="1.0" encoding="utf-8"?>
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
<robot name="URDF 3.0">
  <link name="base_link">
    <inertial>
      <origin xyz="-0.0597485302559153 0.0141254257572485 0.10587011505937" rpy="0 0 0" />
      <mass value="11.1719906867681" />
      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
    </inertial>
    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
  </link>
  <link name="FL">
    <inertial>
      <origin xyz="-5.79677020457608E-07 0.0151323328436038 -5.00752536880533E-07" rpy="0 0 0" />
      <mass value="0.0950105358602906" />
      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
    </inertial>
    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
  </link>
  <joint name="FL" type="revolute">
    <origin xyz="0.19407 -0.13018 -0.02" rpy="0 1.4875 -1.5708" />
    <parent link="base_link" />
    <child link="FL" />
    <axis xyz="0 1 0" />
    <limit lower="0" upper="0" effort="0" velocity="0" />
  </joint>
  <link name="BL">
    <inertial>
      <origin xyz="-5.78404988932357E-07 0.0151323328747486 -4.99227772125105E-07" rpy="0 0 0" />
      <mass value="0.0950105281619692" />
      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
    </inertial>
    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
  </link>
  <joint name="BL" type="revolute">
    <origin xyz="0.19138 0.1398 -0.018649" rpy="0 -0.1784 -1.5708" />
    <parent link="base_link" />
    <child link="BL" />
    <axis xyz="0 1 0" />
    <limit lower="0" upper="0" effort="0" velocity="0" />
  </joint>
  <link name="BR">
    <inertial>
      <origin xyz="-5.77761134434862E-07 0.0151323328879169 -4.98109920907264E-07" rpy="0 0 0" />
      <mass value="0.0950105229485309" />
      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
    </inertial>
    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
  </link>
  <joint name="BR" type="revolute">
    <origin xyz="-0.31799 0.13858 -0.02" rpy="3.1416 -0.28431 -1.5708" />
    <parent link="base_link" />
    <child link="BR" />
    <axis xyz="0 1 0" />
    <limit lower="0" upper="0" effort="0" velocity="0" />
  </joint>
  <link name="FR">
    <inertial>
      <origin xyz="-5.7776113457364E-07 0.0151323328879173 -4.98109921490131E-07" rpy="0 0 0" />
      <mass value="0.0950105229485304" />
      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
    </inertial>
    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
  </link>
  <joint name="FR" type="revolute">
    <origin xyz="-0.31797 -0.13018 -0.02" rpy="-3.1416 0.88964 -1.5708" />
    <parent link="base_link" />
    <child link="FR" />
    <axis xyz="0 1 0" />
    <limit lower="0" upper="0" effort="0" velocity="0" />
  </joint>
  <link name="Roller">
    <inertial>
      <origin xyz="-0.0618941629050755 2.53963516883005E-15 -8.88178419700125E-16" rpy="0 0 0" />
      <mass value="0.353139548782225" />
      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
    </inertial>
    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
  </link>
  <joint name="Roller" type="revolute">
    <origin xyz="0 -0.18256 0.04334" rpy="1.5708 0 0" />
    <parent link="base_link" />
    <child link="Roller" />
    <axis xyz="-1 0 0" />
    <limit lower="0" upper="0" effort="0" velocity="0" />
  </joint>
  <link name="ML">
    <inertial>
      <origin xyz="1.73472347597681E-16 -0.00250000000000033 -6.93889390390723E-18" rpy="0 0 0" />
      <mass value="0.129817069335416" />
      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
    </inertial>
    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
  </link>
  <joint name="ML" type="revolute">
    <origin xyz="0.030419 0.032759 -0.051995" rpy="1.5708 0 0" />
    <parent link="base_link" />
    <child link="ML" />
    <axis xyz="0 -1 0" />
    <limit lower="0" upper="0" effort="0" velocity="0" />
  </joint>
  <link name="MR">
    <inertial>
      <origin xyz="-1.66533453693773E-16 -0.00249999999999968 -2.77555756156289E-17" rpy="0 0 0" />
      <mass value="0.129817069335416" />
      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
    </inertial>
    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
  </link>
  <joint name="MR" type="revolute">
    <origin xyz="-0.15985 0.032114 -0.051034" rpy="1.5708 0 0" />
    <parent link="base_link" />
    <child link="MR" />
    <axis xyz="0 -1 0" />
    <limit lower="0" upper="0" effort="0" velocity="0" />
  </joint>
</robot>

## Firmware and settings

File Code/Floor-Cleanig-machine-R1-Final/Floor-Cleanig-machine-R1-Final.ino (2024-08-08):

// This is the code for our floor cleaning machine. Which build for Desig protype project. This code fully owned by Group R1, Sasindu malhara (2022/E/126)

// Define pins
#define L1 2
#define L2 4
#define LENB 3

#define R1 5
#define R2 7
#define RENB 6

#define Roller 8
#define MOP 9
#define Pump 12
#define Dry 11

#define Usfl_Echo A0
#define Usfl_Trig A1

#define Usfr_Echo 10
#define Usfr_Trig 13

#define Usl_Echo A2
#define Usl_Trig A3

#define Usr_Echo A4
#define Usr_Trig A5

int motor_speed = 255;
int autoModeOn = 0;
char incomingByte;
bool pumpState = false;
const long pumpOnTime = 1000; 
const long pumpOffTime = 2000; 
int obstacledistance = 30;
bool FpumpState = false;


float pred[3];

void setup() {
  pinMode(Pump, OUTPUT);
  pinMode(MOP, OUTPUT);
  pinMode(Roller, OUTPUT);
  pinMode(Dry, OUTPUT);

  pinMode(Usfl_Trig, OUTPUT); 
  pinMode(Usfl_Echo, INPUT);

  pinMode(Usfr_Trig, OUTPUT); 
  pinMode(Usfr_Echo, INPUT);

  pinMode(Usl_Trig, OUTPUT); 
  pinMode(Usl_Echo, INPUT);

  pinMode(Usr_Trig, OUTPUT); 
  pinMode(Usr_Echo, INPUT);

  Serial.begin(9600); 
}


void loop()
{

  switch(autoModeOn)
  {
    case 0:
    manualMode();   
    break;

    case 1 :
    automaticMode();     
    break;
  }
}


void automaticMode() {

  motor_speed = 255;

  if (Serial.available() > 0)   //check if any data is available
  {
    incomingByte = Serial.read();   //read incoming data
    Serial.println(incomingByte);

    if (incomingByte == 'X'){
      Serial.println("Stop");
      digitalWrite(L1, LOW); 
      digitalWrite(L2, LOW);
      digitalWrite(R1, LOW);
      digitalWrite(R2, LOW);
      autoModeOn = 0;

    }
  }

  pred[0]= readUsf();
  pred[1]= readUsl();
  pred[2]= readUsr();
   for (int i = 0; i < 3; i++) {
        Serial.println(pred[i]);
    }
  int prediction = predict(pred);
  Serial.println(prediction);
  switch(prediction){

    case 0:
    turn_l();
    break;

    case 1:
    turn_r();
    break;

    case 2:
    move_b();
    break;

    case 3:
    move_f();
    break;
  }
  
}


void manualMode()
{ 
  if (pumpState == true && FpumpState == true){
    pump();
    }
    

  if (Serial.available() > 0)   //check if any data is available
  {
    incomingByte = Serial.read();   //read incoming data
    Serial.println(incomingByte);
  }

  switch(incomingByte)    //based on received character execute respective commands
  {
    case 'A':
    autoModeOn = 1;
    incomingByte='*';
    break;

    case 'F':
    Serial.println("Forward");
    digitalWrite(L1, LOW); 
    analogWrite(L2, motor_speed);
    analogWrite(R1, motor_speed);
    digitalWrite(R2, LOW);
    FpumpState = true;
    break;

    case 'f':
    Serial.println("Stop");
    digitalWrite(L1, LOW); 
    digitalWrite(L2, LOW);
    digitalWrite(R1, LOW);
    digitalWrite(R2, LOW);
    pumpState = false;
    break;
    
    case 'B':
    Serial.println("Backward");
    digitalWrite(L2, LOW); 
    analogWrite(L1, motor_speed);
    analogWrite(R2, motor_speed);
    digitalWrite(R1, LOW);
    pumpState = false;
    break;
    
    case 'b':                                                                                                          
    Serial.println("Stop");
    digitalWrite(L1, LOW); 
    digitalWrite(L2, LOW);
    digitalWrite(R1, LOW);
    digitalWrite(R2, LOW);
    pumpState = false;
    break;
    
    case 'L':
    Serial.println("Left");
    analogWrite(L1, motor_speed); 
    digitalWrite(L2, LOW);
    analogWrite(R1, motor_speed);
    digitalWrite(R2, LOW);
    pumpState = false;
    break;
    
    case 'l':
    Serial.println("Stop");
    digitalWrite(L1, LOW); 
    digitalWrite(L2, LOW);
    digitalWrite(R1, LOW);
    digitalWrite(R2, LOW);
    pumpState = false;
    break;

    case 'R':
    Serial.println("Right");
    digitalWrite(L1, LOW); 
    analogWrite(L2, motor_speed);
    digitalWrite(R1, LOW);
    analogWrite(R2, motor_speed);
    pumpState = false;
    break;
    
    case 'r':
    Serial.println("Stop");
    digitalWrite(L1, LOW); 
    digitalWrite(L2, LOW);
    digitalWrite(R1, LOW);
    digitalWrite(R2, LOW);
    pumpState = false;
    break;

    case 'S':
    Serial.println("Stop");
    digitalWrite(L1, LOW); 
    digitalWrite(L2, LOW);
    digitalWrite(R1, LOW);
    digitalWrite(R2, LOW);
    pumpState = false;
    break;

    case 'N':
    Serial.println("Pump ON");
    pumpState = true;
    break;
    
    case 'n':
    Serial.println("Pump OFF");
    pumpState = false;
    digitalWrite(Pump, LOW);
    break;

    case 'M':
    digitalWrite(MOP, HIGH);
    break;
    
    case 'm':
    digitalWrite(MOP, LOW); 
    break;

    case 'K':
    digitalWrite(Roller, HIGH);
    break;
    
    case 'k':
    digitalWrite(Roller, LOW); 
    break;

    case 'Q':
    digitalWrite(Dry, HIGH);
    break;
    
    case 'q':
    digitalWrite(Dry, LOW); 
    break;

    case '1':
    motor_speed = 155;
    break;
    
    case '2':
    motor_speed = 205;
    break;
    
    case '3':
    motor_speed = 255;
    break;
    
    delay(500);
  }
}



// Auto mode functions
  
void move_f() {
  Serial.println("Forward");
  digitalWrite(L1, LOW); 
  analogWrite(L2, motor_speed);
  analogWrite(R1, motor_speed);
  digitalWrite(R2, LOW);
  digitalWrite(Roller, HIGH);
  digitalWrite(MOP, HIGH);
  digitalWrite(Dry, HIGH);
  pump();                                                                                                                                                                            
}

void move_b() {
  Serial.println("Backward");
  digitalWrite(Roller, LOW);
  digitalWrite(MOP, LOW);
  digitalWrite(Dry, LOW);
  while (readUsl() == 1 && readUsr() ==1 ){
  digitalWrite(L2, LOW); 
  analogWrite(L1, motor_speed);
  analogWrite(R2, motor_speed);
  digitalWrite(R1, LOW);

  if (Serial.available() > 0)   //check if any data is available
  {
    incomingByte = Serial.read();   //read incoming data
    Serial.println(incomingByte);

    if (incomingByte == 'X'){
      autoModeOn = 0;
      break;
    }
  }

  }
  if (readUsl == 0){
    turn_l();
  }else{
    turn_r();
  }


}

void turn_r() {
  Serial.println("Right");
  digitalWrite(L1, LOW); 
  analogWrite(L2, motor_speed);
  digitalWrite(R1, LOW);
  analogWrite(R2, motor_speed);
  digitalWrite(Roller, LOW);
  digitalWrite(MOP, LOW);
  digitalWrite(Dry, LOW);
} 

void turn_l() {
  Serial.println("Left");
  analogWrite(L1, motor_speed); 
  digitalWrite(L2, LOW);
  analogWrite(R1, motor_speed);
  digitalWrite(R2, LOW); 
  digitalWrite(Roller, LOW);
  digitalWrite(MOP, LOW);
  digitalWrite(Dry, LOW);
}


int readUsf() {
  digitalWrite(Usfl_Trig, LOW);
  delayMicroseconds(20);
  digitalWrite(Usfl_Trig, HIGH);
  delayMicroseconds(100);
  digitalWrite(Usfl_Trig, LOW);
//  distance= duration*0.034/2;
  int distancel = microsecondsToCentimeters(pulseIn(Usfl_Echo, HIGH));

  digitalWrite(Usfr_Trig, LOW);
  delayMicroseconds(20);
  digitalWrite(Usfr_Trig, HIGH);
  delayMicroseconds(100);
  digitalWrite(Usfr_Trig, LOW);
//  distance= duration*0.034/2;
  int distancer = microsecondsToCentimeters(pulseIn(Usfr_Echo, HIGH));

  if(distancel == 0)Serial.println(distancel);
  if(distancer == 0)Serial.println(distancer);

  int reading;
  if(distancel < obstacledistance || distancer < obstacledistance){
    reading = 1.0;
  }else{
    reading = 0;
  }
  return reading;
}

int readUsr() {
  digitalWrite(Usr_Trig, LOW);
  delayMicroseconds(20);
  digitalWrite(Usr_Trig, HIGH);
  delayMicroseconds(100);
  digitalWrite(Usr_Trig, LOW);
//  distance= duration*0.034/2;
  int distance = microsecondsToCentimeters(pulseIn(Usr_Echo, HIGH));
  if(distance == 0)Serial.println(distance);
  int reading;
  if(distance < obstacledistance){
    reading = 1.0;
  }else{
    reading = 0;
  }
  return reading;
}

int readUsl() {
  digitalWrite(Usl_Trig, LOW);
  delayMicroseconds(20);
  digitalWrite(Usl_Trig, HIGH);
  delayMicroseconds(100);
  digitalWrite(Usl_Trig, LOW);
//  distance= duration*0.034/2;
  int distance = microsecondsToCentimeters(pulseIn(Usl_Echo, HIGH));
  if(distance == 0)Serial.println(distance);
  int reading;
  if(distance < obstacledistance){
    reading = 1.0;
  }else{
    reading = 0;
  }
  return reading;
}

long microsecondsToCentimeters(long microseconds) {
   return microseconds / 29 / 2;
}




void pump(){
  Serial.println("PumpON");
  digitalWrite(Pump, HIGH);
  delay(pumpOnTime);
  digitalWrite(Pump, LOW);
  Serial.println("PumpOFF");
  // delay (pumpOffTime);
  }


                    int predict(float *x) {
                        uint8_t votes[4] = { 0 };
                        // tree #1
                        if (x[0] <= 0.5) {
                            votes[3] += 1;
                        }

                        else {
                            if (x[2] <= 0.5) {
                                votes[1] += 1;
                            }

                            else {
                                if (x[1] <= 0.5) {
                                    votes[0] += 1;
                                }

                                else {
                                    votes[2] += 1;
                                }
                            }
                        }

                        // tree #2
                        if (x[0] <= 0.5) {
                            votes[3] += 1;
                        }

                        else {
                            if (x[2] <= 0.5) {
                                votes[1] += 1;
                            }

                            else {
                                if (x[1] <= 0.5) {
                                    votes[0] += 1;
                                }

                                else {
                                    votes[2] += 1;
                                }
                            }
                        }

                        // tree #3
                        if (x[2] <= 0.5) {
                            if (x[1] <= 0.5) {
                                if (x[0] <= 0.5) {
                                    votes[3] += 1;
                                }

                                else {
                                    votes[1] += 1;
                                }
                            }

                            else {
                                if (x[0] <= 0.5) {
                                    votes[3] += 1;
                                }

                                else {
                                    votes[1] += 1;
                                }
                            }
                        }

                        else {
                            if (x[1] <= 0.5) {
                                if (x[0] <= 0.5) {
                                    votes[3] += 1;
                                }

                                else {
                                    votes[0] += 1;
                                }
                            }

                            else {
                                if (x[0] <= 0.5) {
                                    votes[3] += 1;
                                }

                                else {
                                    votes[2] += 1;
                                }
                            }
                        }

                        // tree #4
                        if (x[0] <= 0.5) {
                            votes[3] += 1;
                        }

                        else {
                            if (x[1] <= 0.5) {
                                if (x[2] <= 0.5) {
                                    votes[1] += 1;
                                }

                                else {
                                    votes[0] += 1;
                                }
                            }

                            else {
                                if (x[2] <= 0.5) {
                                    votes[1] += 1;
                                }

                                else {
                                    votes[2] += 1;
                                }
                            }
                        }

                        // tree #5
                        if (x[1] <= 0.5) {
                            if (x[2] <= 0.5) {
                                if (x[0] <= 0.5) {
                                    votes[3] += 1;
                                }

                                else {
                                    votes[1] += 1;
                                }
                            }

                            else {
                                if (x[0] <= 0.5) {
                                    votes[3] += 1;
                                }

                                else {
                                    votes[0] += 1;
                                }
                            }
                        }

                        else {
                            if (x[0] <= 0.5) {
                                votes[3] += 1;
                            }

                            else {
                                if (x[2] <= 0.5) {
                                    votes[1] += 1;
                                }

                                else {
                                    votes[2] += 1;
                                }
                            }
                        }

                        // tree #6
                        if (x[0] <= 0.5) {
                            votes[3] += 1;
                        }

                        else {
                            if (x[2] <= 0.5) {
                                votes[1] += 1;
                            }

                            else {
                                if (x[1] <= 0.5) {
                                    votes[0] += 1;
                                }

                                else {
                                    votes[2] += 1;
                                }
                            }
                        }

                        // tree #7
                        if (x[2] <= 0.5) {
                            if (x[0] <= 0.5) {
                                votes[3] += 1;
                            }

                            else {
                                votes[1] += 1;
                            }
                        }

                        else {
                            if (x[0] <= 0.5) {
                                votes[3] += 1;
                            }

                            else {
                                if (x[1] <= 0.5) {
                                    votes[0] += 1;
                                }

                                else {
                                    votes[2] += 1;
                                }
                            }
                        }

                        // tree #8
                        if (x[1] <= 0.5) {
                            if (x[2] <= 0.5) {
                                if (x[0] <= 0.5) {
                                    votes[3] += 1;
                                }

                                else {
                                    votes[1] += 1;
                                }
                            }

                            else {
                                if (x[0] <= 0.5) {
                                    votes[3] += 1;
                                }

                                else {
                                    votes[0] += 1;
                                }
                            }
                        }

                        else {
                            if (x[0] <= 0.5) {
                                votes[3] += 1;
                            }

                            else {
                                if (x[2] <= 0.5) {
                                    votes[1] += 1;
                                }

                                else {
                                    votes[2] += 1;
                                }
                            }
                        }

                        // tree #9
                        if (x[1] <= 0.5) {
                            if (x[0] <= 0.5) {
                                votes[3] += 1;
                            }

                            else {
                                votes[0] += 1;
                            }
                        }

                        else {
                            if (x[0] <= 0.5) {
                                votes[3] += 1;
                            }

                            else {
                                if (x[2] <= 0.5) {
                                    votes[1] += 1;
                                }

                                else {
                                    votes[2] += 1;
                                }
                            }
                        }

                        // tree #10
                        if (x[2] <= 0.5) {
                            if (x[0] <= 0.5) {
                                votes[3] += 1;
                            }

                            else {
                                votes[1] += 1;
                            }
                        }

                        else {
                            if (x[1] <= 0.5) {
                                if (x[0] <= 0.5) {
                                    votes[3] += 1;
                                }

                                else {
                                    votes[0] += 1;
                                }
                            }

                            else {
                                if (x[0] <= 0.5) {
                                    votes[3] += 1;
                                }

                                else {
                                    votes[2] += 1;
                                }
                            }
                        }

                        // tree #11
                        if (x[2] <= 0.5) {
                            if (x[1] <= 0.5) {
                                if (x[0] <= 0.5) {
                                    votes[3] += 1;
                                }

                                else {
                                    votes[1] += 1;
                                }
                            }

                            else {
                                if (x[0] <= 0.5) {
                                    votes[3] += 1;
                                }

                                else {
                                    votes[1] += 1;
                                }
                            }
                        }

                        else {
                            if (x[1] <= 0.5) {
                                if (x[0] <= 0.5) {
                                    votes[3] += 1;
                                }

                                else {
                                    votes[0] += 1;
                                }
                            }

                            else {
                                if (x[0] <= 0.5) {
                                    votes[3] += 1;
                                }

                                else {
                                    votes[2] += 1;
                                }
                            }
                        }

                        // tree #12
                        if (x[0] <= 0.5) {
                            votes[3] += 1;
                        }

                        else {
                            if (x[2] <= 0.5) {
                                votes[1] += 1;
                            }

                            else {
                                if (x[1] <= 0.5) {
                                    votes[0] += 1;
                                }

                                else {
                                    votes[2] += 1;
                                }
                            }
                        }

                        // tree #13
                        if (x[0] <= 0.5) {
                            votes[3] += 1;
                        }

                        else {
                            if (x[2] <= 0.5) {
                                votes[1] += 1;
                            }

                            else {
                                if (x[1] <= 0.5) {
                                    votes[0] += 1;
                                }

                                else {
                                    votes[2] += 1;
                                }
                            }
                        }

                        // tree #14
                        if (x[2] <= 0.5) {
                            if (x[0] <= 0.5) {
                                votes[3] += 1;
                            }

                            else {
                                votes[1] += 1;
                            }
                        }

                        else {
                            if (x[0] <= 0.5) {
                                votes[3] += 1;
                            }

                            else {
                                if (x[1] <= 0.5) {
                                    votes[0] += 1;
                                }

                                else {
                                    votes[2] += 1;
                                }
                            }
                        }
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

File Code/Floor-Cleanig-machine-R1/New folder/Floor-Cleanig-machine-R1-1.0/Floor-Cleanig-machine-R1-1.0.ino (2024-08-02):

// This is the code for our floor cleaning machine. Which build for Desig protype project. This code fully owned by Group R1, Sasindu malhara (2022/E/126)

// Define pins
#define L1 2
#define L2 4
#define LENB 3

#define R1 5
#define R2 7
#define RENB 6

#define Roller 8
#define MOP 9
#define Pump 12
#define Dry 11

#define Usf_Echo A0
#define Usf_Trig A1

#define Usl_Echo A2
#define Usl_Trig A3

#define Usr_Echo A4
#define Usr_Trig A5

int motor_speed = 255;
int autoModeOn = 0;
char incomingByte;
bool pumpState = false;
const long pumpOnTime = 500; // Pump on duration in milliseconds
const long pumpOffTime = 2000; // Pump off duration in milliseconds
int obstacledistance = 30;

unsigned long prev_t = 0;
unsigned long curr_t = 0;

int readings[100];
byte mapsize = 100;
int i = 1;
byte unit_TH = 20000;
byte unit_TV = 15000;

byte l=0, b=0, r=0;

byte base_size = 0;

void setup() {
  pinMode(Pump, OUTPUT);
  pinMode(MOP, OUTPUT);
  pinMode(Roller, OUTPUT);
  pinMode(Dry, OUTPUT);
  initializeUS();
  Serial.begin(9600); 
}


void loop()
{

  switch(autoModeOn)
  {
    case 0:
    manualMode();   
    break;

    case 1 :
    automaticMode();     
    break;
    delay(500);
  }
}


void automaticMode() {

  incomingByte = Serial.read();   //read incoming data
  if (incomingByte == 'X')
  {autoModeOn = 0;
  incomingByte='*';
  } else {

  Serial.println("I is: ");
  Serial.print(i);
  l=0;
  b=0;
  r=0;
  if(readUsf() > obstacledistance) {
      if(i%2 != 0){
        prev_t = millis();
        while(readUsf() > obstacledistance){

          incomingByte = Serial.read();   //read incoming data
          if (incomingByte == 'X')
          {autoModeOn = 0;
          incomingByte='*';
          break;}

          Serial.println("Inside 1");
          move_f();
        }
      } else {
        if (i % 4  != 0){
          turn_r();
          move_oneblock();
          if(look_l() > obstacledistance){
            turn_l();
            prev_t = millis();
            while(readUsf() > obstacledistance){

              incomingByte = Serial.read();   //read incoming data
              if (incomingByte == 'X')
              {autoModeOn = 0;
              incomingByte='*';
              break;}

              Serial.println("Inside 2");
              move_f();
            }
            curr_t = millis();
//            addReading(i);
            l = (curr_t - prev_t)/unit_TH;
            turn_r();
            Serial.println("Inside 3");
            move_f();
            delay(curr_t - prev_t);
          }
          turn_r();
          i++;
        } else {
          turn_l();
          move_oneblock();
          if(look_r()> obstacledistance){
            turn_r();
            prev_t = millis();
            while(readUsf() > obstacledistance){

              incomingByte = Serial.read();   //read incoming data
              if (incomingByte == 'X')
              {autoModeOn = 0;
              incomingByte='*';
              break;}

              Serial.println("Inside 4");
              move_f();
            }
            curr_t = millis();
//            addReading(i);
            r = (curr_t - prev_t)/unit_TH;
            turn_l();
            Serial.println("Inside 5");
            move_f();
            delay(curr_t - prev_t);
          }
          turn_l();
          i++;
        }
      }
    } else {
      move_s();
      curr_t = millis();
      b = (curr_t - prev_t)/unit_TH;
//      addReading(i);
      i++;
      if(look_r() > obstacledistance){
        turn_r();
      }
    }
  }
}


void manualMode()
{
  if (Serial.available() > 0)   //check if any data is available
  {
    incomingByte = Serial.read();   //read incoming data
    Serial.println(incomingByte);
  }
  if (pumpState){
    pump();
  }


  switch(incomingByte)    //based on received character execute respective commands
  {
    case 'A':
    autoModeOn = 1;
    incomingByte='*';
    break;

    case 'F':
    Serial.println("Forward");
    digitalWrite(L1, LOW); 
    analogWrite(L2, motor_speed);
    analogWrite(R1, motor_speed);
    digitalWrite(R2, LOW);
    break;

    case 'f':
    Serial.println("Stop");
    digitalWrite(L1, LOW); 
    digitalWrite(L2, LOW);
    digitalWrite(R1, LOW);
    digitalWrite(R2, LOW);
    break;
    
    case 'B':
    Serial.println("Backward");
    digitalWrite(L2, LOW); 
    analogWrite(L1, motor_speed);
    analogWrite(R2, motor_speed);
    digitalWrite(R1, LOW);
    break;
    
    case 'b':
    Serial.println("Stop");
    digitalWrite(L1, LOW); 
    digitalWrite(L2, LOW);
    digitalWrite(R1, LOW);
    digitalWrite(R2, LOW);
    break;
    
    case 'L':
    Serial.println("Left");
    analogWrite(L1, motor_speed); 
    digitalWrite(L2, LOW);
    analogWrite(R1, motor_speed);
    digitalWrite(R2, LOW);
    break;
    
    case 'l':
    Serial.println("Stop");
    digitalWrite(L1, LOW); 
    digitalWrite(L2, LOW);
    digitalWrite(R1, LOW);
    digitalWrite(R2, LOW);
    break;

    case 'R':
    Serial.println("Right");
    digitalWrite(L1, LOW); 
    analogWrite(L2, motor_speed);
    digitalWrite(R1, LOW);
    analogWrite(R2, motor_speed);
    break;
    
    case 'r':
    Serial.println("Stop");
    digitalWrite(L1, LOW); 
    digitalWrite(L2, LOW);
    digitalWrite(R1, LOW);
    digitalWrite(R2, LOW);
    break;

    case 'S':
    Serial.println("Stop");
    digitalWrite(L1, LOW); 
    digitalWrite(L2, LOW);
    digitalWrite(R1, LOW);
    digitalWrite(R2, LOW);
    break;

    case 'N':
    pumpState = true;
    break;
    
    case 'n':
    pumpState = false;
    digitalWrite(Pump, LOW);
    break;

    case 'M':
    digitalWrite(MOP, HIGH);
    break;
    
    case 'm':
    digitalWrite(MOP, LOW); 
    break;

    case 'K':
    digitalWrite(Roller, HIGH);
    break;
    
    case 'k':
    digitalWrite(Roller, LOW); 
    break;

    case 'Q':
    digitalWrite(Dry, HIGH);
    break;
    
    case 'q':
    digitalWrite(Dry, LOW); 
    break;

    case '1':
    motor_speed = 155;
    break;
    
    case '2':
    motor_speed = 205;
    break;
    
    case '3':
    motor_speed = 255;
    break;
    
    delay(5000);
  }
}




void move_s() {
  Serial.println("Stop");
  digitalWrite(L1, LOW); 
  digitalWrite(L2, LOW);
  digitalWrite(R1, LOW);
  digitalWrite(R2, LOW);
  digitalWrite(Roller, LOW);
  digitalWrite(MOP, LOW);
  digitalWrite(Dry, LOW);
} 
  
void move_f() {
  Serial.println("Forward");
  digitalWrite(L1, LOW); 
  analogWrite(L2, motor_speed);
  analogWrite(R1, motor_speed);
  digitalWrite(R2, LOW);
  digitalWrite(Roller, HIGH);
  digitalWrite(MOP, HIGH);
  digitalWrite(Dry, HIGH);
  pump();                                                                                                                                                                            
}
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

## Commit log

2024-07-31 pump,roller,mop,dry functions added
2024-08-01 add pump delay for manual mode
2024-08-02 pump new update inside function
2024-08-02 manual mode changed
    [Floor cleaning machine ML dataset .csv]
2024-08-02 pump and check auto updated
2024-08-03 ML Model
    [Floor cleaning machine ML dataset .csv]
2024-08-05 pump updated manual mode
